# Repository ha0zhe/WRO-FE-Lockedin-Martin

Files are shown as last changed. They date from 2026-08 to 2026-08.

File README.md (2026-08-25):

# WRO-FE-Lockedin-Martin

# Team information:
Team ID: FE-XXX-01
Team name: Lockedin Martin
Team members:
- Yuan Hao Zhe
- Liu Xinji
- Om Joshi Vaibhav

# Overview
Welcome to the github repository of team Lockedin Martin for WRO 2026.

The Wro FE competition consists of 2 rounds: the open round and the obstacle round. in the open round, the vehicle must autonomously drive 3 laps on a track with no obstacles and stop at its starting position. in the obstacle round, the vehicle must navigate 3 laps on a track containing red and green traffic signs, turning right when encountering a red sign and left when encountering a green sign. For the obstacle round, the vehicle must also autonomously parallel-park in a parking lot that is demarcated by magenta blocks. 

All the information about the vehicle, including technical specifications, the design process and how it works, can be found in the engineering journal. The wiring diagram can be found in the schemes folder, the CAD models under the models folder, and the code in the src folder. 

Our team uses  dual microcontroller setup for this competition: the Openmv H7 plus for blob detection and navigation. and the RP2040 zero for sensor reading. code for specific functions of the H7, such as UART reading and blob detection, can be found in the files with names beginning with H7_ in the src folder. the RP2040 sensor reading code can be found in the same folder, compiled in one script.

# Build details
The chassis is printed at 0.20 mm nozzle diameter using PLA filament. The number of walls we used is 4 and the infill percentage is 15%. The infill pattern is grid.

Sandpaper may need to be used when assembling the chasis, if the fit is too tight.

The screws and nuts used to mount the steering mechanism must be snug, but not tight enough to hinder the actuation of the steering mechanism. 

The electronics are all connected using jumper cables without the need for soldering, with the exception of the power distribution board, which is direct soldered to the step down buck converters. More details can be found in the engineering journal. when soldering, keep the iron temperature at about 350 degrees and use liberal amounts of flux. be careful when holding the components with alligator clips as they might damage some delicate components on the board.

To charge the Lipo battery, a dedicated Lipo charger, such as the HOTA D6 Pro, must be used to avoid damaging the battery. do not discharge the battery below 3v and do not overcharge it over 4.2v

# Software details

Openmv IDE is used to run and debug the H7 code, while Arduino IDE is used for the RP2040. Thonny could also be used for the H7 if the camera is not needed e.g. when testing the UART.

Openmv IDE's threshold is used to tune the CIELAB color thresholds used in blob detection. As much as possible, refer to Openmv's excellent documentation and tutorials.

For the code to be saved on the H7, you must save it on the H7's internal memory as main.py. This can be done manually, through dragging and dropping files in file manager, or it can be done in the Openmv IDE in File --> save script under Openmv cam

To setup Thonny for Openmv H7 plus:
1. Install Thonny, then Run → Select interpreter.
2. Choose "MicroPython (generic)" from the interpreter dropdown (there's no dedicated OpenMV entry — generic is correct since it just      talks raw REPL over serial).
3. Pick the port your H7 Plus enumerates as (or leave on auto-detect if it's the only device attached).
4. Click OK — Thonny's shell should show the >>> REPL prompt, and the Files pane will let you browse/edit files directly on the camera's internal flash or SD card.

To setup Openmv Ide for Openmv H7 plus:
1. Download and install OpenMV IDE from openmv.io/pages/download — no separate board package needed, unlike Arduino.
2. Plug in the H7 Plus via USB, click Connect (bottom-left plug icon).
3. If prompted with a firmware update on first connect — accept it. It'll ask whether to erase the internal filesystem: say No if you      have scripts stored on internal flash you want to keep, otherwise Yes for a clean start. It flashes over DFU automatically (green       LED fades in/out during the process) and reconnects when done.
4. Open helloworld_1.py or your own script, hit the Play (bottom-left run) button — you'll get a live frame buffer view alongside           serial console output, which is what makes it good for tuning your blob-detection thresholds.

To setup Arduino Ide for RP2040 Zero:
1. Add the board package URL. Open Arduino IDE → File → Preferences → paste this into "Additional Boards Manager URLs":
   https://github.com/earlephilhower/arduino-pico/releases/download/global/package_rp2040_index.json
   (If you already have another URL      there, e.g. for ESP32, separate them with a comma.)
3. Install the core. Tools → Board → Boards Manager → search "pico" → install "Raspberry Pi Pico/RP2040/RP2350" by Earle F. Philhower,     III. This is the community core (not the official Arduino-Mbed one) — it's the one with full RP2040 peripheral support (PIO,            multicore, etc.) and is what you're already using per your Serial/Serial1/Serial2 debugging.
4. Select the board. Tools → Board → Raspberry Pi RP2040 Boards → Waveshare RP2040 Zero. If your installed core version doesn't list it    specifically, "Generic RP2040" also works fine for a Zero.
5. Upload. Hold BOOT, plug in via USB (or hold BOOT and tap RESET if already connected), release once the RPI-RP2 drive appears.           Arduino should now show a COM/tty port — select it and upload normally. After the first proper Arduino sketch is flashed, subsequent    uploads happen automatically over USB without needing BOOT mode again. If not, hold down the boot button, connect the RP2040, select
   and connect to the DFU port n the tools menu. After uploading the code, you should be able to connect via COM port in the same          tools menu
   
# Tips and tricks

1. Make sure all pin headers are tightly connected, especially for I2C. loose connections will degrade the high frequency clock signal and prevent it from working
2. Make sure to tighten all screws and nuts before testing. not doing so will result in inconsistent turn radii.
3. Make sure to wipe the TOF lens before testing it, to prevent oils from interfering with the reading
4. When tuning the color thresholds, use the narrowest thresholds that can still correctly identify the blocks under varying lighting conditions (e.g on different positions on the track)
5. do not touch the IMU while it is being tared.

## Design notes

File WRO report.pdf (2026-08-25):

## Engineering Journal

Team ID: FE-XXX-01
Team name: Lockedin Martin
Team members:
- Yuan Hao Zhe
- Liu Xinji
- Om Joshi vaibhav

## BOM

Component type | component | quantity
1x Main MCU | Openmv H7 plus | https://e.tb.cn/h.8k547RCXRMKPPMn?tk=YBlXTWm NGnR CA381
1x Sensor reading MCU | Waveshare RP2040 zero | https://e.tb.cn/h.8PjmAA171s06Ows?tk=IHOLTWmm ZNu HU591
2x TOF sensor | VL53L1X | https://e.tb.cn/h.8lDQ4xvxufmwdAn?tk=JVRuTWmoiV x MF937
1x Motor driver | DRV8874 | https://e.tb.cn/h.8PjKGGh9RIypMOC?tk=HPOsTWmo E9O CZ001 「D
1x IMU | BNO085 | https://kuriosity.sg/products/9dof-9-axis-accelerometer -gyroscope-magnetic-field-sensor-bno085?_pos=1&_ sid=b334db9a9&_ss=r
1x motor | 1020 coreless motor | https://e.tb.cn/h.8955D6mjnewGMLc?tk=FXHUTWmp d1r MF278
4x wheels | POLOLU 34mm silicone wheels | https://e.tb.cn/h.8lDlnlgMV7zfWEh?tk=kgliTWmKsee CZ005
1x servo | SG90 servo | https://kuriosity.sg/products/servo-motor-sg92r-180-36

| | 0-sg90-upgrade?_pos=1& _sid=28d788176&_ss=r
1x battery | TATTU R-LINE 2S 500MAH battery | https://hobbysquare.com.sg/collections/battery-2s-7-4v/products/tattu-r-line-7-4v-2s-550mah-95c-lipo-micro-battery-xt30
1x Buck converter | 5v buck converter | https://kuriosity.sg/products/dc-dc-step-down-buck-converter-3-3v-5v-12v-3a?variant=51054170308921
1x Buck converter | 3.3v buck converter | https://kuriosity.sg/products/dc-dc-step-down-buck-converter-3-3v-5v-12v-3a?_pos=3&_sid=1854b2fae&_ss=r
1x Battery lead | XT30 female lead | https://hobbysquare.com.sg/products/xt30-connector-male-and-female-2-pairs?_pos=4&_sid=2305c2fce&_ss=r
4x bearing | 2mm ID, 5mm OD, 2.5mm thick bearing | https://e.tb.cn/h.8k5j7aNDYUkgbZ3?tk=3Qu4TWmt2i L HU926
1x Motor gear | 10 tooth gear, 0.5mm ID | https://e.tb.cn/h.8k5SP1lUNwkpewx?tk=18RbTWmrF V0 MF278
1x Shaft gear | 30 tooth gear, 2mm ID | https://e.tb.cn/h.8957CbRobZdnOfa?tk=G1rCTWmsS 3b MF937 「0
2x Metal shaft | 2mm by 12mm stainless steel rod | https://e.tb.cn/h.895RU63o9vwlXqi?tk=8JWuTWmH8 mV MF168

## Mechanical design

Steering mechanism selection
- In an ideal steering mechanism, the path of all the wheels trace out circles that centres on the same point, which is the instantaneous centre of rotation (ICR) of the vehicle. This ensures that all wheels are tangential to the circular path that they travel, hence preventing lateral tire slippage. This reduces vibration and ensuring that the turning behaviour of the vehicle remains predictable
- A neutral steering mechanism has both front wheels being parallel to one another, while an ackermann steering mechanism has the inner wheel (the one closer to the ICR) turning more than the outer wheel. A reverse ackermann steering mechanism has the outer wheel turning more than the inner wheel.
- When a vehicle with a neutral steering mechanism turns rightwards, the centre of the circle that the inner (right) wheel traces lies to the right of that which the outer (left) wheel traces, resulting in lateral wheel slippage.
- An ackermann steering assembly remedies this problem by making sure the inner wheel turns more than the outer wheel. A reverse ackermann mechanism exacerbates this problem

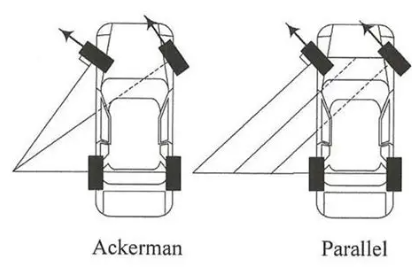
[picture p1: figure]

- A neutral or reverse ackermann mechanism offers different advantages. During high-speed cornering, weight shifts dramatically to the outer front tire. The outer tire generates the vast majority of cornering force and operates at a higher slip angle, while the unloaded inner tire contributes very little. Turning the outer tire more aggressively using a reverse ackermann mechanism maximizes peak cornering grip, improving high speed cornering performance.

- For our application, where precise and predictable low speed control is necessary to navigate around obstacles and to parallel park, the ideal steering mechanism would be the ackermann steering mechanism.

Ackermann mechanism key dimensions

In a standard ackermann steering mechanism, the front wheels are mounted to a steering rods that are connected by a steering linkage. The steering rods are angled in such a way that lines drawn through them intersect in the middle of the rear axle.

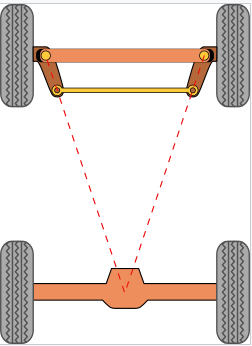
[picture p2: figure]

Motor and wheel sizing (from our LATEX document)

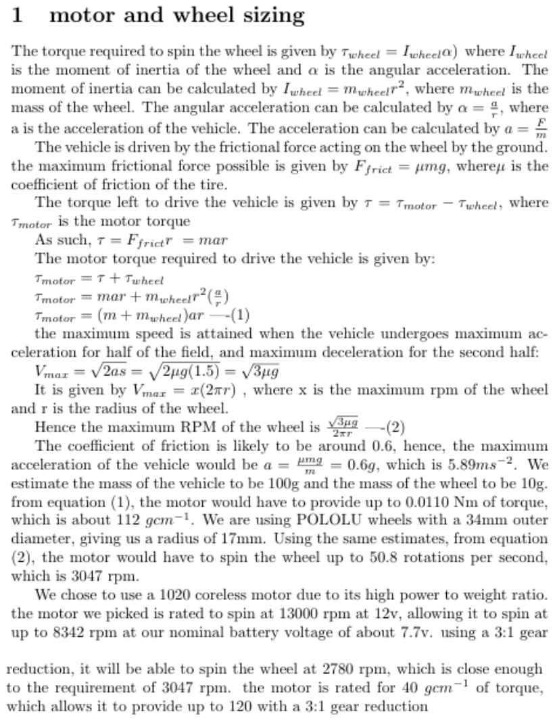
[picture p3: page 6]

Optimal CG location (from LATEX document)

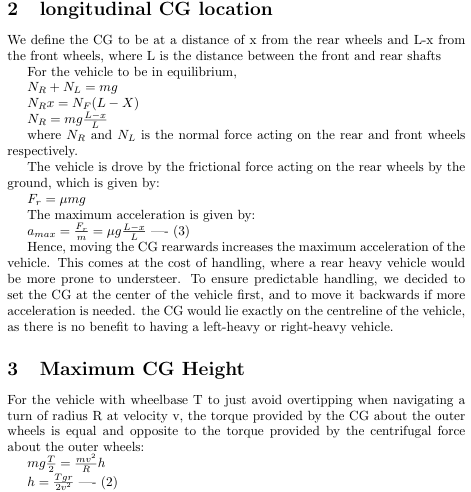
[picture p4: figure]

Mass requirement
- During braking, the motor driver shorts its terminals together, turning the motor into a generator and dissipating the vehicles kinetic energy.
- A lighter vehicle would brake better as it has less kinetic energy to dissipate
- Hence we aim to keep our vehicle mass as low as possible.

Chassis sizing(from our LATEX document)

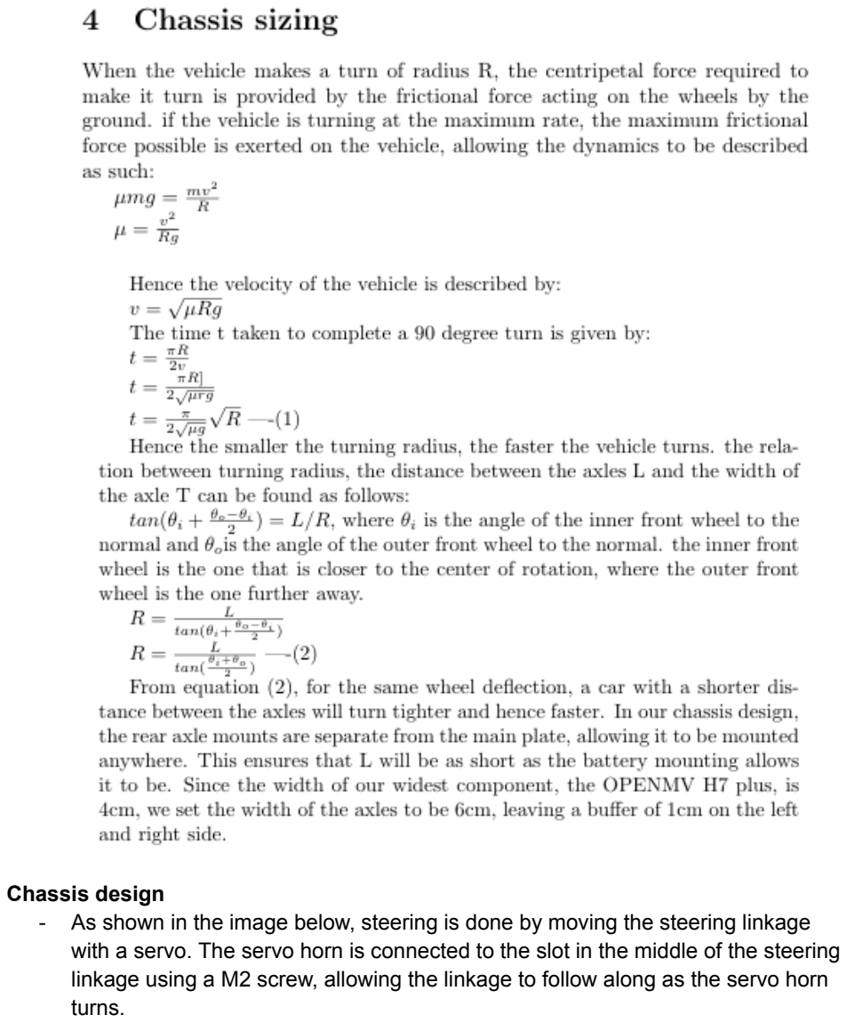
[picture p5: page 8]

Chassis design
- As shown in the image below, steering is done by moving the steering linkage with a servo. The servo horn is connected to the slot in the middle of the steering linkage using a M2 screw, allowing the linkage to follow along as the servo horn turns.

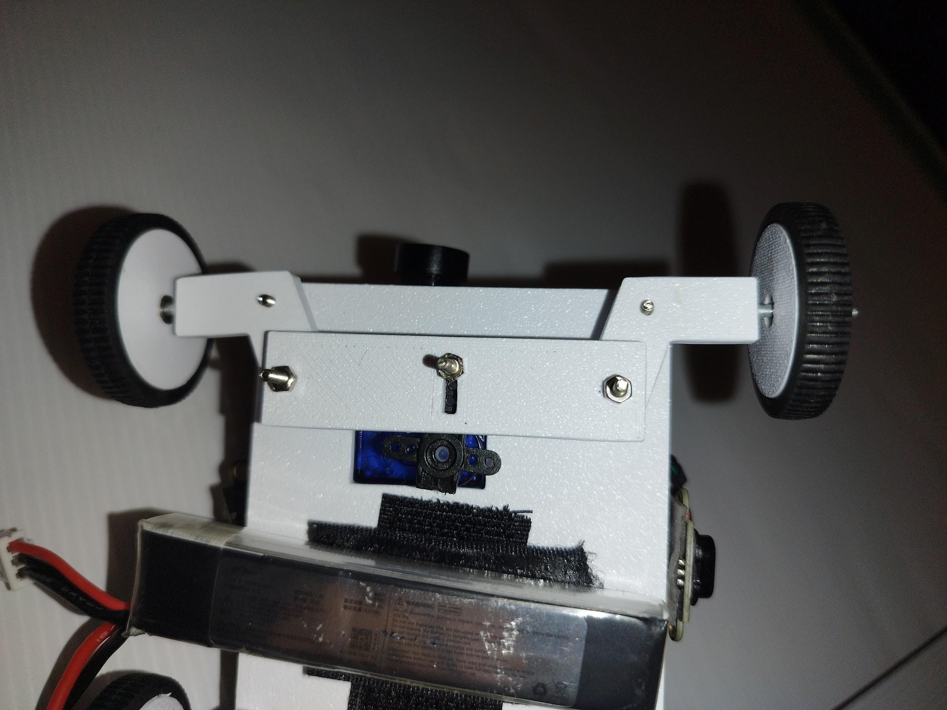
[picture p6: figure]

- As the chassis is designed before the mounting of the electronics is finalised, one of the key considerations behind our chassis design is to make it as modular as possible, so that it can accommodate as many configurations of electronics as possible. To accomplish this, we decided to mount the steering pins and linkage using M2 screws and nuts instead of 3d printing a mount. This allows us to freely adjust the distance of the steering mechanism from the main plate by using different numbers of nuts, hence allowing it to be connected to many different servos.

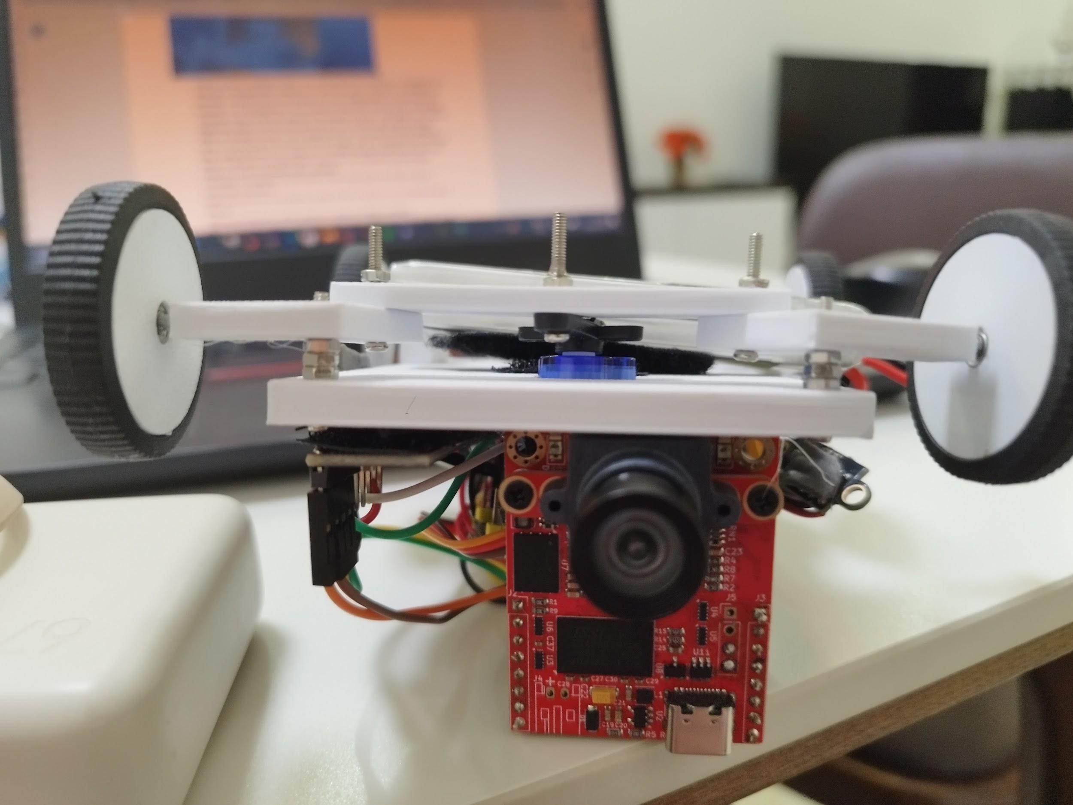
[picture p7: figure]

- The mounts for the rear shaft is also separate from the main plate, allowing them to be swapped out if different gears need to be used. The motor, front and rear shaft mounts, and servo are mounted using hot glue, making it easily removable with a penknife.
- The front wheels are mounted to a 2mm by 15mm metal shaft that is then inserted to the front steering arm. We cut it down to size from the 12mm by 2mm shaft used for the rear wheels
- The battery is mounted on the bottom of the main plate, to make room for electronics on the top.
- After trial and error, we ended up using 0.2mm of tolerance for all parts to get a snug fit
- We used bearings for all the wheels to minimize rolling resistance
- We used a 2mm stainless steel metal rod for the shaft because 3d printed shafts would be too weak. We used off-the-shelf plastic gears for the gear reduction because they are machined more precisely than 3d printed parts, reducing the friction between the gear teeth.
- All electronics are mounted using velcro, for easy removal

## Power Management

Voltage draw
- All electronics are powered by 3.3V and 5V buck converters which step down battery voltage to 3.3V and 5V respectively
- VL53L1X must be powered off 3.3V for the logic level to be 3.3v, as the RP2040 zero is not 5V tolerant
- All other components can be powered off 5V, but we chose to power the rp2040 off 3V to free up space on the 5V rail and improve wire management
- The BNO085 is powered off the 3.3V regulator of the OpenmvH7 plus due to its proximity to it, hence freeing up space on the 3.3V rail and improving wire management
component | Input voltage tolerance | Logic level tolerance | Input voltage | Logic level
DRV8874 motor driver | 4.5-37V | 1.8V-5.5V input | 5V and battery voltage
Openmv H7 Plus | 3.6-5V | 3.3V output Input up to 5V | 5V
RP2040 Zero | 2.5-3.3V (3V3 pin) 4.3-5.5V (5V/USB pin) | 3.3V input and output | 3.3V
VL53L1X TOF sensor | 2.6v-5.5V | 3.3V-5V input and output, output level shifted to Power supply voltage | 3.3V
BNO085 IMU | 3.0v-5.0V | 3.3V-5V input and output, output level shifted to Power supply voltage | 3.3V
SG90 servo | 4.8v-6.0V | 3.3V to 5V input | 5V

3.3V

Current draw

component | Maximum current draw
DRV8874 motor driver | 2.1A continuous, 4.4A peak with current limiting enabled
Openmv H7 Plus | ~350 mA

RP2040 zero | ~100 mA (40-50mA when both ARM Cortex-M0+ cores run at 125 MHz, 50mA max from GPIO pins)
VL53L1X TOF | ~20 mA continuous, 40 mA when the laser fires
BNO085 | ~20 mA
SG90 servo | ~750 mA when stalled
TOTAL | ~3.36 A continuous, ~5.70 A peak

Buck converter specifications

The the 5V buck converter powers the SG90 servo and the OpenmvH7 plus, which powers the BNO085 IMU, while the 3.3V buck converter powers the RP2040 and two VL53L1X TOF sensors. The DRV8874 is powered directly by the battery. Both buck converters are able to supply the required current.

Buck converter type | Input voltage | Maximum output current | Maximum current drawn
5V | 7-26V | 1.8A | 1.12A
3V | 5.3-26V | 2.5A | 0.14A

## Buck converter setup

- The two buck converters are soldered to a perfboard as such

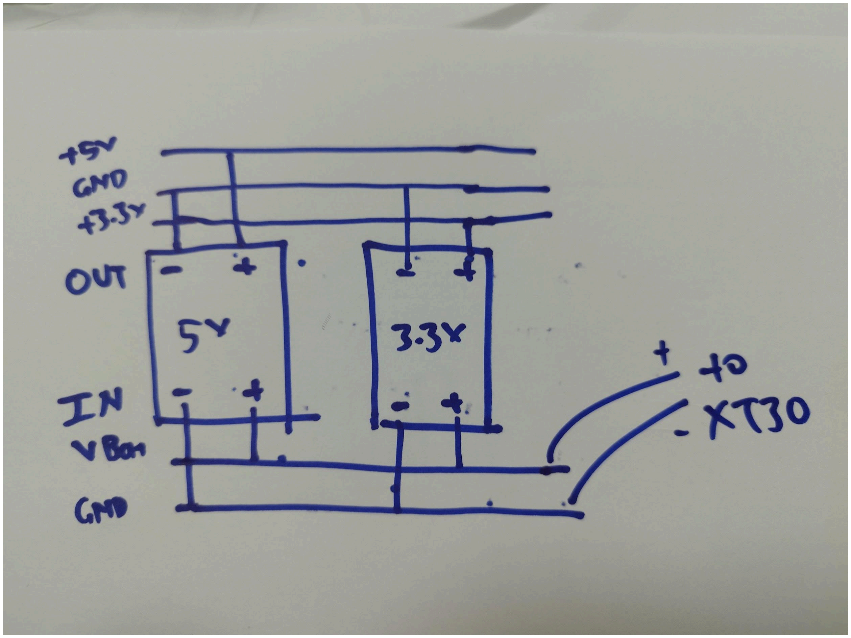
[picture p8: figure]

- The positive input of both buck converters are soldered to the same rail, which is connected to the positive lead of the battery via an XT30 female connector
- Likewise, the negative input of both buck converters are soldered to the same rail
- The negative output of both buck converters are soldered to the same rail
- The 3.3v output and 5v output are soldered to the rails above and below the GND rail respectively

BATTERY TYPE SELECTION
The ideal battery must be:
1. supply a high enough voltage and current throughout the duration of the run to be able to easily power all components on the vehicle
2. be light so total weight is reduced, allowing for faster braking and more predictable cornering
3. be thin enough so the car can sit lower to the ground, reducing the CG height and hence improving the turn radius

Hence we decided to use lithium polymer (Lipo) battery packs as they are generally lighter and smaller than lithium ion or double A battery packs of the same capacity and voltage.
Lipo batteries are also widely available, coming in a wide range of voltages, current ratings and capacities, making it easier to find one that is optimal

Characteristics of lipo batteries:

- A lipo battery has a maximum voltage of 4.2v per cell when fully charged and can be discharged down to a minimum voltage of approximately 3.0v, below which the battery becomes permanently damaged due to electrochemical effects.
- the battery C rating shows its approximate current rating: maximum continuous current = capacity (in Ah) x C rating
- as the battery discharges, the open circuit voltage per cell decreases plateaus at about 3.8 volts per cell, approximately following this graph:

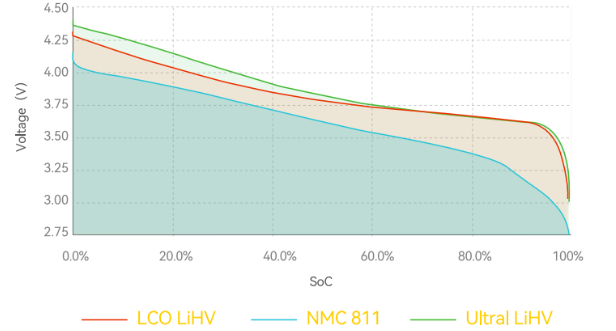
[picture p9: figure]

- due to battery internal resistance, the terminal voltage (v = V-RI) will always be lower than the open circuit voltage when current is flowing
- the internal resistance increases if the system draws sustained and high current. lithium ions must move through electrolytes, separators and electrodes in order to react and supply electricity. As this process takes time, continuously drawing high current may deplete the supply of lithium electrons in certain parts of the battery, resulting in chemical disequilibrium, increasing the battery internal resistance and causing the terminal voltage to sag even more. This effect is not significant if current draw is much lower than the maximum rating, hence the importance of choosing a battery with a high C rating.

Lipo selection: Tattu R-Line 550mAh 2s

As the maximum continuous current draw is 3.36A, the vehicle would draw a maximum of 168 mAh of charge over a 3 minute run time, which is 15.3% of the total charge capacity (550mAh x
2) of the battery. This gives us an open circuit voltage of approximately 3.9V per cell at the end of the run, with a total open circuit voltage of 7.8V. Using a high estimate of internal resistance of 30mOhm and the maximum peak current of 5.70A, the maximum voltage sag would be 0.03 x

5.70 = 1.01 V. since the battery is rated for 95C of continuous current draw, which is much higher than the maximum current draw of our vehicle, we expect the internal resistance to stay constant during the run. Hence the minimum terminal voltage during the run would be about 7.7V, leaving a 0.7v buffer to the minimum input voltage of the 5v buck converter. Hence, we are confident that the Tattu R-Line 550mah 2s will be able to easily power all of our components across the duration of the run.

## Electronics

## Sensor architecture

- We use one microcontroller to read sensor data and another one to run the blob detection and navigation algorithms, and to control the vehicle movement. This is done to increase the speed of the control loop.
- Reading a VL53L1X sensor takes up to 20ms using the longest ranged detection mode. Reading two sensors takes anywhere from 20ms to 40ms, depending on how synchronised the two sensors are – something that varies with each run. Since sensor reading is blocking, with other parts of the code waiting for it to finish, doing this using the same microcontroller that runs blob detection and navigation code would slow down the control loop by at least 20ms.
- In comparison, if a separate microcontroller is reading sensor data, both the sensor reading and the blob detection + navigation code can run simultaneously, with the data being sent over by UART once it is collected. Since reading an approximately 40 byte data packet via a UART with 115200 baudrate only takes about 3.5 milliseconds, a dual microcontroller setup would be much faster than a single microcontroller.

## Choice of components

When choosing components, we went with 2 main criteria
1. Smaller is better
- our chassis calculations show that smaller vehicles are able to turn faster and tighter, shaving time off our runtime and improving maneuverability
2. Simpler is better
- Based on our previous experience, a simpler system has less points of failure and is easier to debug, leading to a more reliable and repairable system

RP2040 zero

The RP2040 zero was chosen for various reasons:
- Size
- The RP2040 zero is one of the smallest microcontrollers that has the functionality that we need. This is due to its innovative design that places pins on 3 sides of the board, while most other microcontrollers only use 2 sides
- Affordability
- The RP2040 zero’s 4 USD price is very affordable compared to alternatives from arduino and STM32, which usually cost at least 10 USD
- Functionality
- It uses a Dual-core Arm Cortex M0+ processor, flexible clock running up to 133 MHz. This is much faster than alternatives like the arduino nano, which only runs up to 16 MHz
- It has 29 × multi-function GPIO pins (20× via edge pinout, others via solder points), 2 × SPI, 2 × I2C, 2 × UART, 4 × 12-bit ADC, 16 × controllable PWM channels
- This is more than our requirements of 1 UART and at least 1 I2C bus, giving us great flexibility in using additional peripherals in the future
- Every GPIO pin can be routed to any of the 8 × Programmable I/O (PIO) state machines. PIO machines are used to quickly and precisely read the quadrature encoder used with the motor.
- Language compatibility and flexibility
- The RP2040 zero can be programmed using c++ in the arduino IDE, something that we are already familiar with. C++ also runs faster as it is a lower level programming language.
- It can be programmed using micropython and Thonny, which may prove useful if we decide to use micropython to keep the code simpler to read, and if its speed is sufficient. One of the team members is also much more experienced in python

Computer vision

- We decided not to use openCV because it requires a single board computer, such as a raspberry pi, running a full linux operating system to set up and use. A single board computer is not only large by itself, it also has a comparatively high power consumption, hence requiring a battery with a higher capacity. This leads to a larger chassis and a higher all up weight, reducing the speed and maneuverability of our vehicle. An operating system, dependency management and toolchains are also needed to run opencv, making it complex to setup and use and hence prone to errors. As we only need to run simple blob detection, we do not need the advanced computer vision and machine learning algorithms provided by opencv, making it overkill for our application
- We decided to go with openmv because it can be run on cheap, low power and compact microcontrollers without the need to install operating systems, and is simple to setup using the openmv IDE. Openmv libraries also have a wide range of algorithms to detect and track simple objects, such as blob detection, line detection, and the rectangle detection that is used to find apriltags. Furthermore, the documentation is excellent, with extensive tutorials and guides.
- We decided to go with the openmvH7 plus because blob detection is relatively simple and does not require the computing power of more modern modules such as the openmv n6. The camera resolution is also greatly improved over the base H7, at 5MP instead of 0.3MP. This allows it to detect the traffic signs from further away and track the centroids of the signs more precisely, hence allowing the vehicle to navigate more precisely. This is especially important since we plan to replace the stock lens with 50 degree FOV with one that has a higher FOV of 105 degrees.
- The openmv h7 plus has 3 pins dedicated hardware PWM pins, 2 uarts and 2 I2C buses, allowing it to interface with all of the peripherals that we need.

Distance sensor
- Distance sensors are mounted to the side of our vehicle for wall detection and avoidance.
- We chose to use Time of flight (TOF) sensors instead of ultrasonic sensors because ultrasonic sensors tend to be unreliable, with fluctuating values and a tendency to malfunction and cause the i2c bus to hang. Using multiple ultrasonic sensors together will also result in interference, further degrading the readings.
- We chose to use the VL53L1X due to its long range and small form factor. Its maximum range is 400cm, which is long enough to detect the walls at the side, even after accounting for the low reflectivity of the matte black surface of the walls, which reduce the range to about 200cm
- The range of the VL53L1X is also adjustable, giving us the option to trade detection range for update rate and resistance to ambient lighting

IMU
- We chose the BNO085 because it has the lowest rotation vector drift rate, about 2 degrees per minute, out of all the options we have, even without having to use the magnetometer. This is done using the Hillcrest Labs' proprietary SH-2 sensor fusion engine (MotionEngine)
- The sensor fusion software uses dynamic gyroscope zero-rate bias estimation to reduce gyroscope drift, and uses an extended kalman filter alongside accelerometer data to produce an accurate angular position.
- This eliminates our dependence on magnetometers, which require careful calibration in every different location, and whose reading is frequently unreliable due to the changing magnetic fields from the motor.

Motor + wheel + encoder
- We chose the POLOLU 34mm wheel because it is available in local electronics stores, making it easy to replace.
- We chose to use a 1020 coreless motor due to its high power to weight ratio and small size (see mobility management for more details)
- We hot glued an encoder designed for N20 gearmotors onto the front shaft of the coreless motor, and attached a gear to the back shaft using superglue. The encoder is mounted on the front shaft due to the motor terminals on the back blocking it.
- N20 gearmotor encoders are more common than other encoders, such as optical encoders, and are likely to have better documentation, hence the choice to use them

Motor driver
- The DRV8874 was chosen because its current rating is high enough to power the motor.
- It is also able to use both the PWM and PH/EN control modes, allowing for flexibility in how we control the motor.
- The documentation behind the motor driver is also extensive, with the datasheet explaining small details such as how the current limiter works

Buck converters
- We used the buck converters from our local electronics shop because it is readily available, making it easy to find replacements if we damage it during soldering, or if one of them is defective

# Wiring diagram

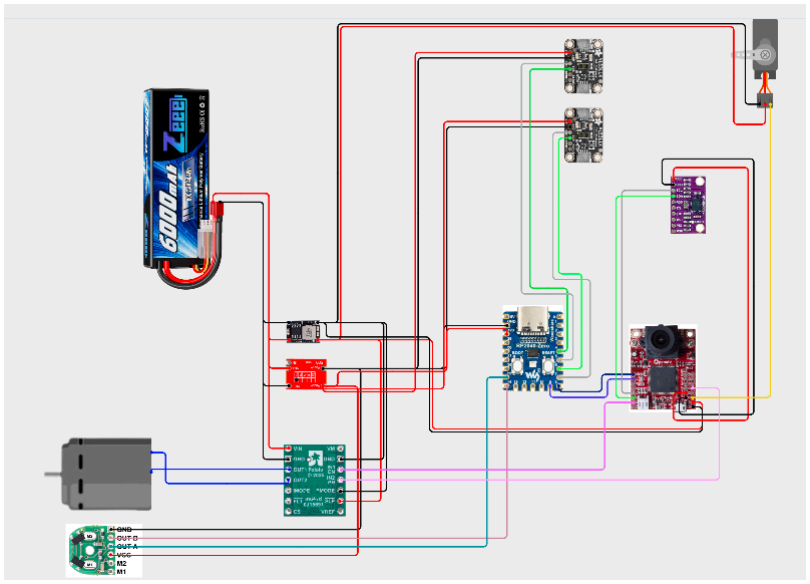
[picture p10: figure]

The wiring diagram for our vehicle can be found here: Cirkit Designer IDE (https://app.cirkitdesigner.com/project/a0f62c62-ac20-4be2-ba1d-bf362a7d67d6)

Rp2040 zero to VL53L1X
The VL53L1X TOF sensor communicates with the RP2040 Zero using I2C. each sensor uses its own i2c bus instead of sharing a bus, to reduce the complexity of our code.
- TOF 1 SDA → GPIO 4 (i2c bus 1 SDA)
- TOF 1 SCL → GPIO 5 (i2c bus 1 SCL)
- TOF 2 SDA → GPIO 6 (i2c bus 2 SDA)
- TOF 2 SCL → GPIO 7 (i2c bus 2 SCL)
The RP2040 zero only has 2 I2C buses, so any additional TOFs used must share an i2c bus. Since all VL53L1X sensors share the same default address, the addresses of all the TOFs on the bus must be reassigned during startup so the i2c bus knows which sensor it is talking to. This can be done by connecting their XSHUT pins to GPIO pins, turning on the sensors one by one using and reassigning their addresses individually.

RP2040 to encoder

- The motor encoder uses quadrature encoding and sends data to the RP2040 using digital HIGH/LOW signals
- It can be read using any GPIO pins on the RP2040 zero, though most encoder libraries require the two pins to be adjacent to one another
- OUT A → GPIO 14
- OUT B → GPIO 15
If the encoder outputs negative values when the vehicle is moving forward, just swap the two connections.

RP2040 to Openmv H7 Plus
- The RP2040 zero communicates with the OpenmvH7 using UART. the RP2040 uses UART bus 1 (GPIO 8 and 9), and the Openmv H7 Plus uses UART bus 1 (P0, P1)
- GPIO 8 (TX1)→ P0(RX1)
- GPIO 9 (RX1)→ P1(TX1)

Openmv H7 Plus to DRV8874
- The Openmv H7 Plus controls the DRV8874 motor driver using Phase/enable mode instead of pwm mode. Pulling the phase pin on the DRV8874 high or low determines the direction that the motor is spinning in, while applying a PWM signal to the enable pin determines the motor speed.
Phase/enable mode is preferable to pwm mode as it has a more linear relationship between PWM duty cycle and motor speed, making it easier to tune the motor speed.
- The PH pin is connected to P9, and the EN pin is connected to P6
- PH → P9
- EN → P6 (PWM signal)
- NOTE: the EN pin on the motor driver and the servo signal wire should not be connected to pins on the OpenmvH7 that share the same timer (eg. P7 and P8), as the frequencies of their PWM signals are different (50hz on the servo, 20kHz on the motor driver), hence requiring separate timers.
- The motor wires are connected to the output pins
- OUT1 → motor terminal
- OUT2 → motor terminal
- 5V must be connected to Vsleep on the DRV8874 to set the current limiting to 4A, and GND must be connected to PMODE on the DRV8874 to enable EN/PH mode.
- Vsleep → 5v output on buck converter
- PMODE → GND on buck converter

Openmv H7 Plus to BNO085
- The BNO085 IMU communicates with the Openmv H7 Plus using I2C. the I2C 2 bus is used.
- SDA → P5 (I2C 2 SDA)
- SCL → P4 (I2C 2 SCL)

Power electronics (see power management for details) Battery voltage
- The DRV8874 is powered off battery voltage
5V buck converter
- 5V buck converter is used to power the Openmv H7 Plus, and the SG90 servo
- Connect all the Vin pins to the 5V rail, and all the ground pins to the ground rail
- 5V must be connected to Vsleep on the DRV8874 to set the current limiting to 4A, and GND must be connected to PMODE on the DRV8874 to enable EN/PH mode.
3.3V buck converter
- 3.3V buck converter is used to power the VL53L1X and the RP2040 Zero
- Connect all the Vin pins to the 3.3V rail, and all the ground pins to the ground rail
- The BNO085 is powered off the 3.3v regulator on the Openmv H7 Plus

## IMU calibration

- The accelerometer and gyroscope of the IMU do not require calibration on start, as they are calibrated at the factory
- The magnetometer can be calibrated by running the calibration code in src, and moving the sensor around in a figure 8 pattern until the magnetometer calibration accuracy level reaches 3.
- For our application, we do not use the magnetometer as the changing magnetic fields from the motor will affect the accuracy of the readings. As such, we take the heading from the game rotation vector output, instead of the rotation vector output on the IMU.

## Color threshold calibration

- The LAB color space is used instead of RGB, as any changes in brightness would affect all 3 of the R,G,B readings, affecting the accuracy of the detection. In LAB color space, the L (lightness) term separates pure brightness from the actual chromatic color, allowing us to account for surface gloss and shadows

- Calibration is done in the OPENMV IDE threshold editor, as follows
- Load the blob detection script onto the board → run the script to capture a image in the frame buffer → go to tools - machine vision- threshold editor → adjust the A and B sliders until the blob you are trying to detect becomes white

## Obstacle management (open)

Start condition:
- Power is supplied to the vehicle by turning on a switch connected to the positive lead of the battery
- A switch connects pin P2 to ground. If the switch is closed, P2 will be pulled low and the start condition would be true. Only then would the vehicle run.

turning methods

We considered 2 main ways to detect the turn direction and turns: using the camera or the side TOF sensors:
- detect turn direction
- using camera:
- check whether orange or blue blob is detected first

OR

- Using side TOF: check which side registers large jump in reading first
- detect turns using
- Side TOF: turn when one side registers large jump in reading
- Camera: turn as soon as either orange or blue blob is detected
- May set a distance delay: turn only when an orange or blue blob is detected and the encoder increases by X counts, hence making sure the vehicle clear the inner walls, no matter the track configuration

Upon further testing, we found that camera blob detection triggers turning more reliably, provided the color thresholds were tuned well.

Since a smaller radius turn also means a faster turn, as shown in the mechanical design section, we use a lower speed when turning.

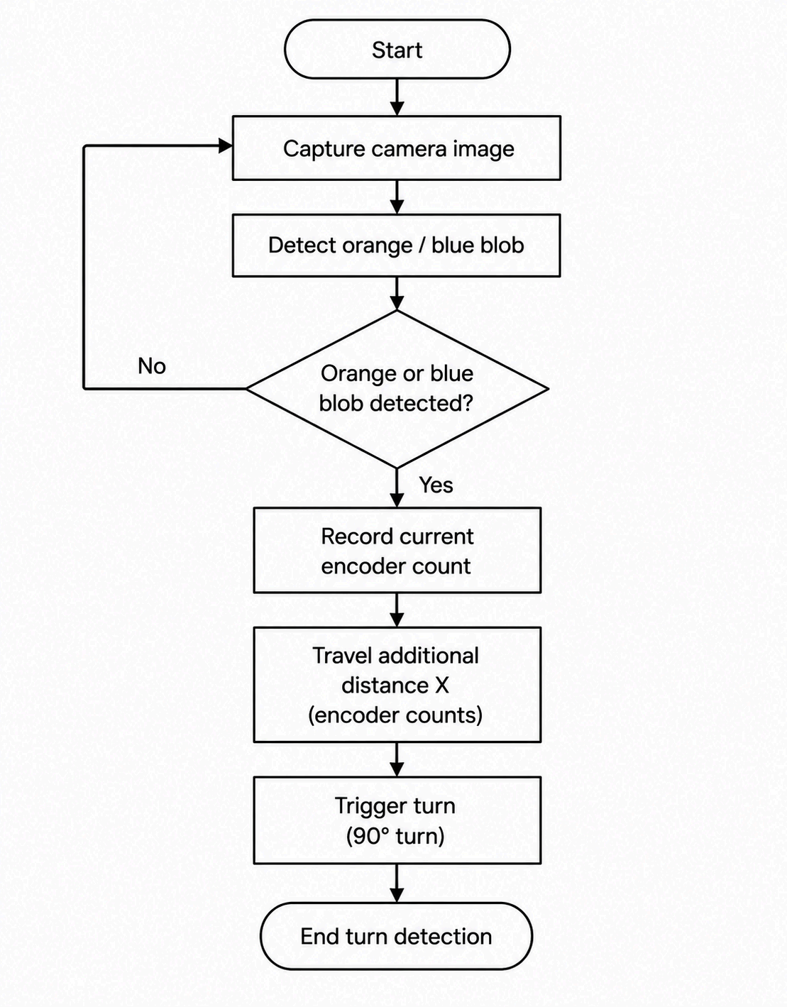
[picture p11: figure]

IMU PID
- Throughout the whole run, we run a PID loop using the IMU heading to ensure that the vehicle remains parallel to the walls
- If we were to hard code the turns wiithout a PID loop, differences in wheel friction, chassis vibration and unpredictable wheel slip would cause the vehicle to fall out of alignment and crash into the walls.

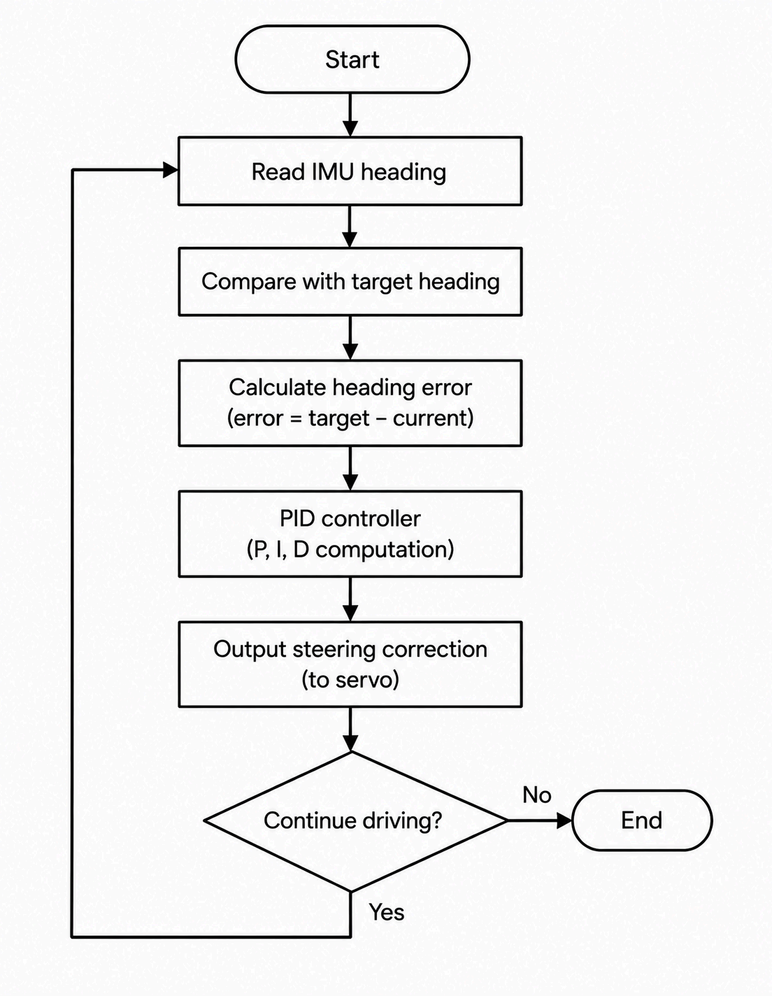
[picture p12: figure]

Corner counting
- We simply count the number of turns registered by theIMU

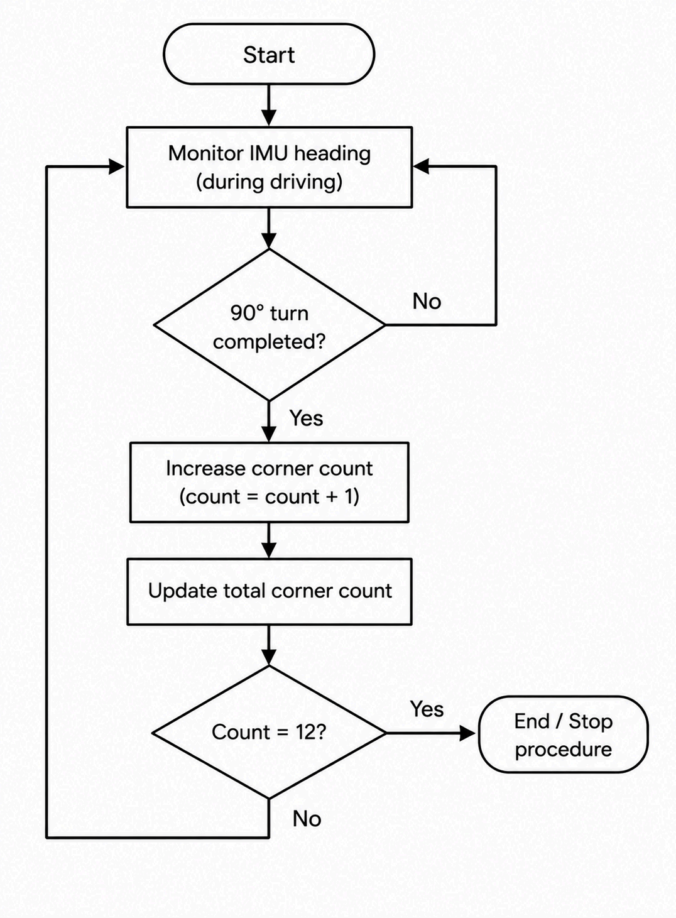
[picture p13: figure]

Driving straight
- Apart from the PID loop, we also use the TOF sensors for wall avoidance:
- If the left TOF registers a reading of less than dmin, the setpoint heading changes by 20 degrees to the right
- If the right TOF registers a reading of less than dmin, the setpoint heading changes by 20 degrees to the left
- The setpoint headings return to normal after the vehicle is more than dmin away from the walls
- This serves as a final failsafe if the IMU PID loop fails to keep the vehicle away from the walls

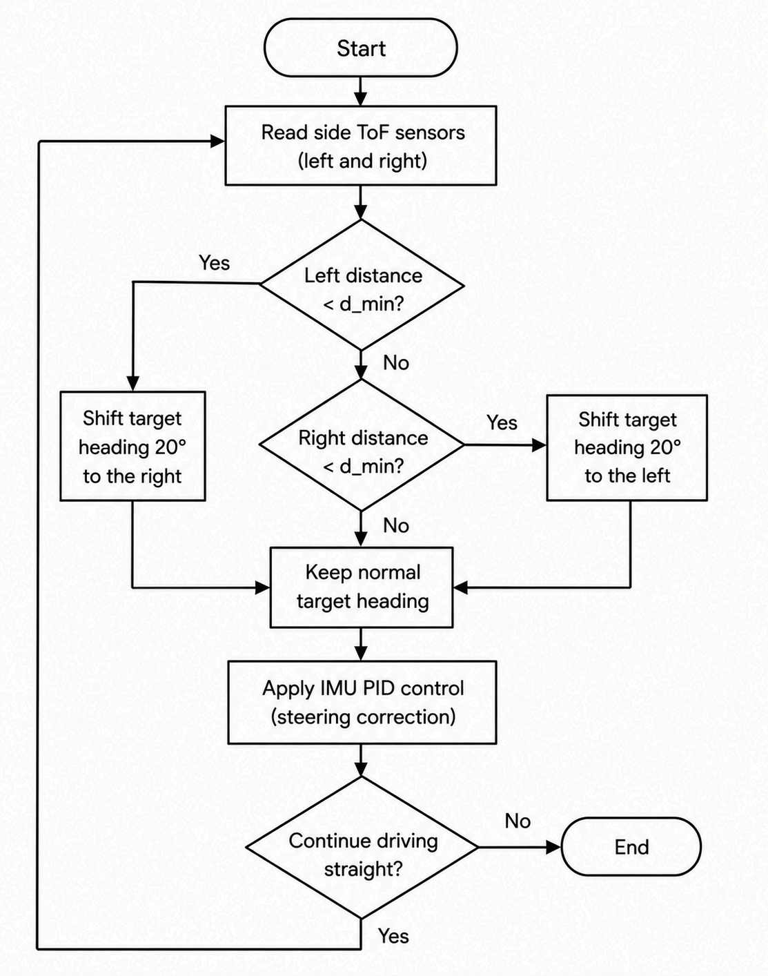
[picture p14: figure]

Stopping
- After 12 corners are detected the vehicle comes to a stop after travelling for a certain number of encoder counts
- The speed is cut in half to ensure that the wheels do not slip, hence giving an accurate encoder reading.

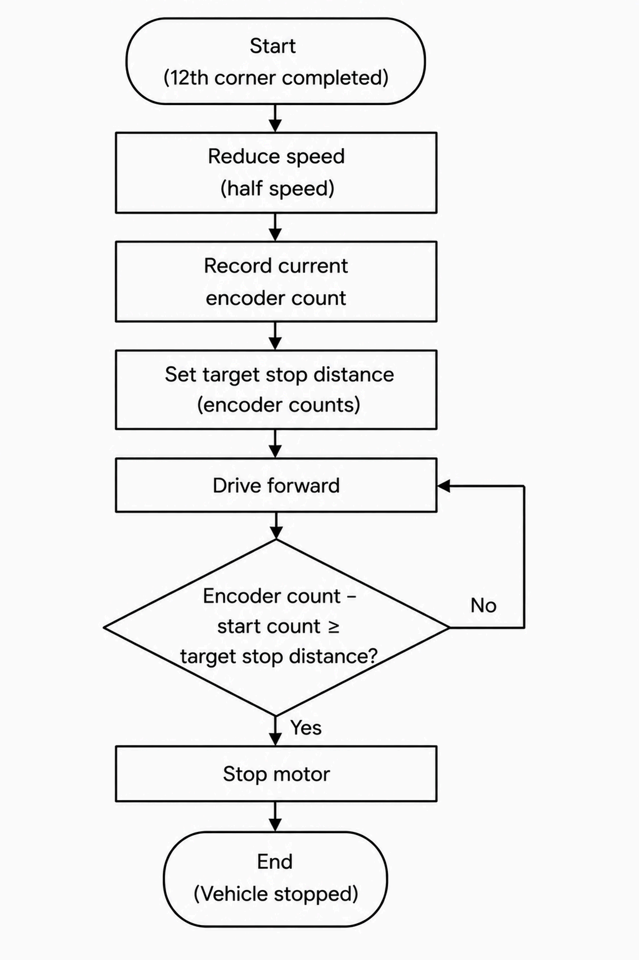
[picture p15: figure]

## Obstacle management (obstacle)

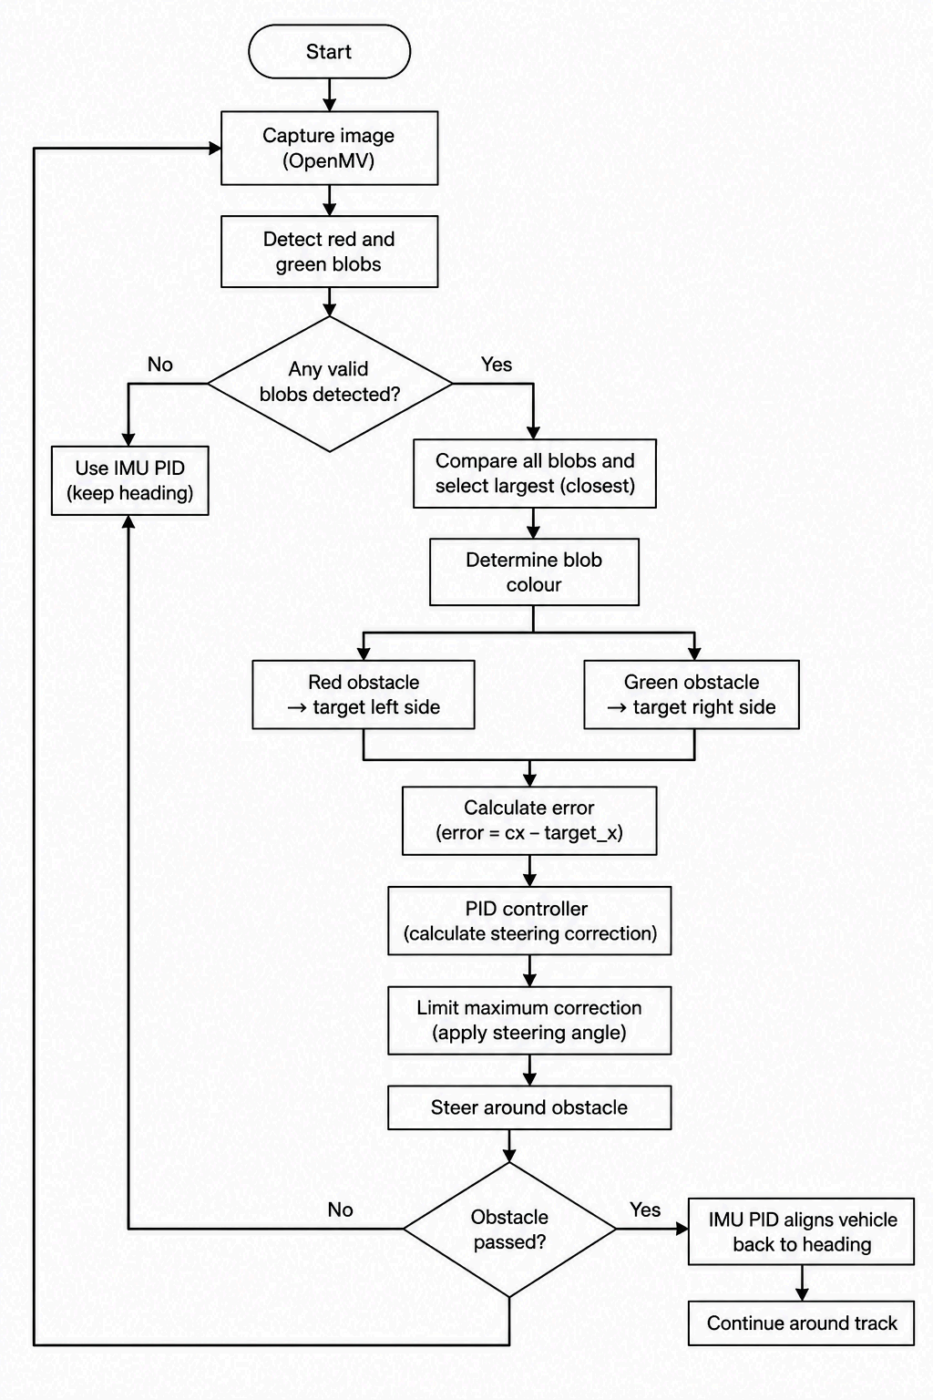
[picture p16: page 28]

1. The red and green traffic signs are detected using the blob detection functions provided by OpenMV. Colour thresholds are used to separate red and green objects from the rest of the camera image.
2. All valid red and green blobs in the camera frame are compared. The blob with the greatest pixel area is selected, as a larger apparent area generally indicates that the traffic sign is closer to the vehicle.
3. Once an obstacle is detected, its colour determines the required passing side. For a red traffic sign, the servo direction is changed so that the block is positioned towards the left side of the camera frame, allowing the vehicle to pass the obstacle on its right. For a green traffic sign, the servo direction is changed so that the block is positioned towards the right side of the frame, allowing the vehicle to pass the obstacle on its left. The vehicle then adjusts servo direction to move back onto its original course.
4. The horizontal position of the detected blob is compared with the required target position, and the resulting error is passed into a PID controller. The controller continuously adjusts the steering servo so that the blob centroid approaches the desired position in the camera image.
5. The steering correction generated by the PID controller is limited to prevent excessively sharp steering commands. As the vehicle moves, a new camera frame is captured and the blob centroid is recalculated. This forms a closed-loop system:

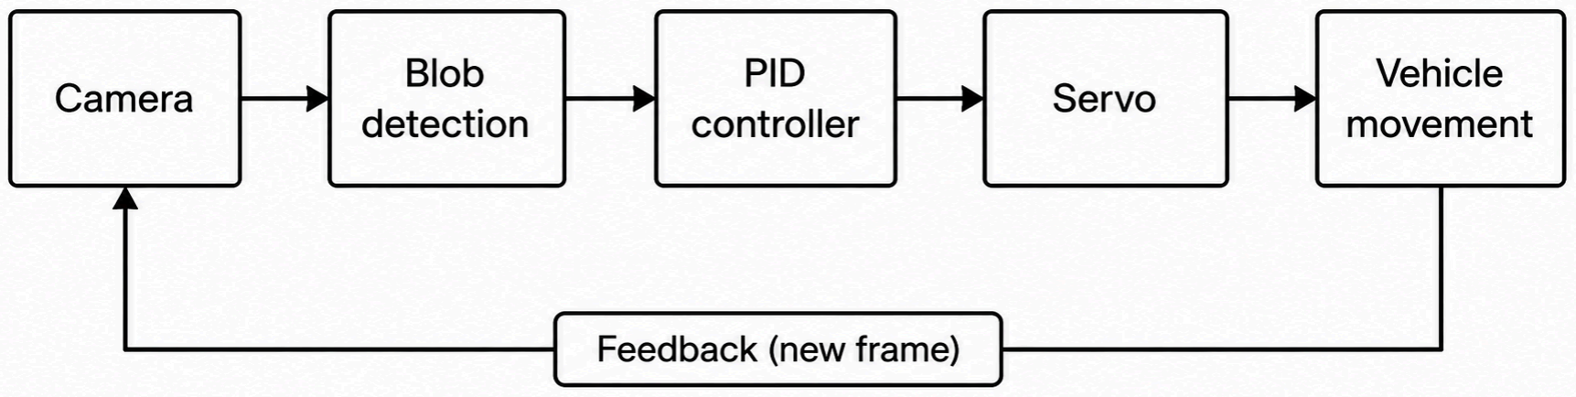
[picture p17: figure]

The process repeats continuously instead of relying on a completely hardcoded avoidance path.

6. The relative size of the blob is also monitored. As the vehicle approaches an obstacle, the blob occupies more pixels in the image. This is done through assessing the height and width in pixels. Once pixel threshold is met, the avoidance protocol is started.
7. After the obstacle has been passed, obstacle guidance is discontinued and control returns to the IMU-based heading controller. The IMU PID controller steers the vehicle back towards its original straight heading so that it travels approximately parallel to the track walls.
8. During turning, if another valid red or green blob is detected while the vehicle is approaching a corner or changing its direction, the vehicle returns to the obstacle-avoidance controller. A 90 degree turn can only be performed when no obstacle is detected.

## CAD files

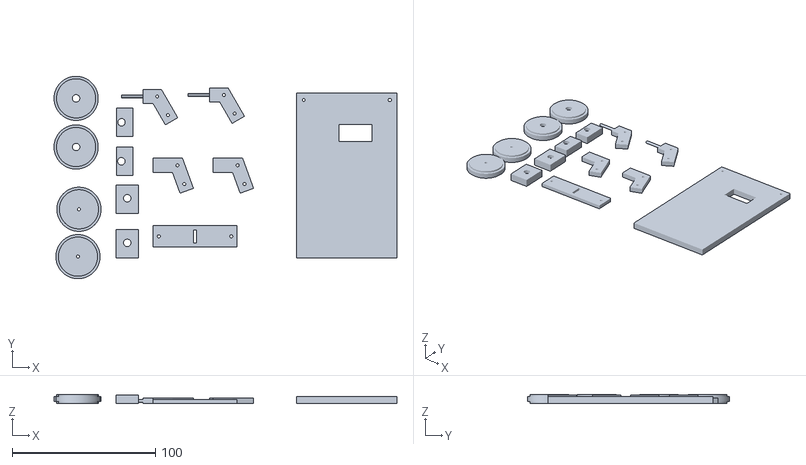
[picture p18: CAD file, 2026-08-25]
models / WRO CHASSIS FINAL.stl
239.1 x 141.1 x 6.60

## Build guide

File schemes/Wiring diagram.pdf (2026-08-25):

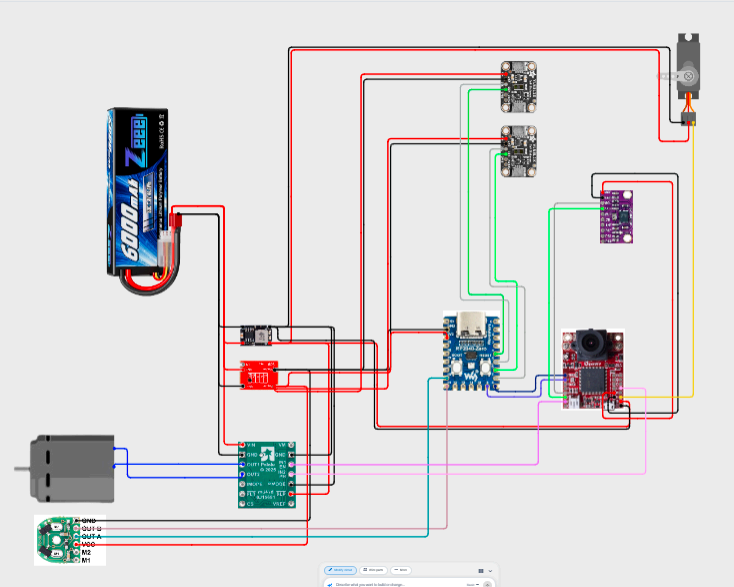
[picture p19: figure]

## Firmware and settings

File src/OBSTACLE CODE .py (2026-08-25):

# ============================================================
# WRO 2026 FUTURE ENGINEERS
# OBSTACLE CHALLENGE
#
# COMPLETE PYTHON CONTROL PROGRAM
#
# Existing hardware ports are UNCHANGED:
#
# UART          = UART(1)
# IMU           = I2C(2)
# Servo         = P8
# Motor DIR     = P9
# Motor PWM     = P6
#
# ============================================================


# ============================================================
# ORIGINAL UART CODE
# ============================================================

from machine import UART
import re


# define variables below

encoder_count = 0
wheel_revolutions = 0
tof0 = 0
tof1 = 0


uart = UART(1, 115200)

uart.init(
    115200,
    bits=8,
    parity=None,
    stop=1)


buf = b""


pattern = re.compile(
    r'encoder count:\s*(\d+),\s*'
    r'tof0:\s*(\d+),\s*'
    r'tof1:\s*(\d+)')


def read_UART():

    global buf, encoder_count, tof0, tof1, wheel_revolutions

    if uart.any() > 0:

        buf += uart.read(
            uart.any())

        if b'\n' in buf:

            line_byte, buf = buf.split(b'\n',1)

            line_string = (line_byte.decode('utf-8').strip())

            match = pattern.search(line_string)

            if match:

                encoder_count = int(match.group(1))

                tof0 = int(match.group(2))

                tof1 = int(match.group(3))

                wheel_rotations = (encoder_count/(28 * 3))

            print("Parsed -> Encoder:",encoder_count,"TOF0:",tof0,"TOF1:",tof1)

        else:

            print("Failed to parse string structure")


# ============================================================
# ORIGINAL IMU CODE
# ============================================================

from machine import I2C, Pin
from utime import ticks_ms, ticks_diff, sleep_ms
import math
from bno08x import *


i2c1 = I2C(
    2,
    freq=100000,
    timeout=200000
)


bno = BNO08X(
    i2c1,
    debug=False
)


print(
    "BNO08x I2C connection : Done\n"
)


bno.enable_feature(
    BNO_REPORT_GAME_ROTATION_VECTOR,
    10
)


bno.set_quaternion_euler_vector(
    BNO_REPORT_GAME_ROTATION_VECTOR
)


print(
    "BNO08x sensors enabling : Done\n"
)


cpt = 0


def read_IMU():

    global cpt

    cpt += 1

    print(
        "cpt",
        cpt
    )

    R, T, P = bno.euler

    print(
        "Euler Angle\tX: {:+.3f}\tY: {:+.3f}\tZ: {:+.3f}".format(
            R,
            T,
            P
        )
    )

    if cpt == 10:

        bno.tare()


# ============================================================
# ORIGINAL SERVO CODE
# ============================================================

from machine import PWM, Pin


servo = PWM(
    Pin("P8"),
    freq=50,
    duty_ns=1_500_000)


def set_position(angle):

    pulse_us = (
        1000
        +
        (angle * 1000)
        //
        180)

    servo.duty_ns(
        pulse_us * 1000)


# Existing examples:
#
# set_position(25)   full right
# set_position(135)  full left
# set_position(80)   centre


# ============================================================
# ORIGINAL MOTOR CODE
# ============================================================

import time
from machine import PWM, Pin


dir_pin = Pin(
    "P9",
    Pin.OUT
)


speed = PWM(
    Pin("P6"),
    freq=20_000,
    duty_u16=0
)


def drive(
    direction,
    speed_percent
):

    dir_pin.value(
        direction
    )

    speed.duty_u16(
        (
            speed_percent
            *
            65535
        )
        //
        100
    )


# ============================================================
#
# NEW WRO OBSTACLE CHALLENGE CODE STARTS HERE
#
# ============================================================


import sensor


# ============================================================
# MOTOR DIRECTION
# ============================================================

FORWARD = 0
REVERSE = 1


# ============================================================
# STEERING
# =========================S===================================

STEERING_RIGHT = 25
STEERING_CENTRE = 80
STEERING_LEFT = 135


MAX_BLOB_STEERING = 40

MAX_IMU_STEERING = 35


# ============================================================
# SPEEDS
# ============================================================

# Slow parking/start speed to reduce wheel slip

LEAVING_SPEED = 50

NORMAL_SPEED =70

AVOID_SPEED = 60

TURN_SPEED = 65

PARKING_SPEED = 60


# ============================================================
# WHEEL / ENCODER
# ============================================================

ENCODER_COUNTS_PER_REV = (
    28 * 3
)


# CHANGE THIS
# Measure your actual wheel diameter

WHEEL_DIAMETER_MM = 34


WHEEL_CIRCUMFERENCE_MM = (
    math.pi
    *
    WHEEL_DIAMETER_MM
)


# ============================================================
# ROUND SETTINGS
# ============================================================

ROUND_TIME_LIMIT_MS = (
    3 * 60 * 1000
)


TARGET_LAPS = 3

TURNS_PER_LAP = 4


# Distance travelled after fourth corner
# before confirming that the lap is complete.

LAP_CONFIRM_DISTANCE_MM = 150


# ============================================================
# LEAVING PARKING LOT
# ============================================================

BACKUP_DISTANCE_MM = 40


RIGHT_TURN_TIME_MS = 900

STRAIGHT_CLEAR_TIME_MS = 800

LEFT_TURN_TIME_MS = 900


# ============================================================
# TOF
# ============================================================

# Change to False if tof0 is physically on RIGHT

TOF0_IS_LEFT = True


WALL_DETECT_DISTANCE_MM = 500


TURN_OPENING_DISTANCE_MM = 800


TURN_OPENING_CONFIRM_MS = 250


# ============================================================
# CAMERA
# ============================================================

IMAGE_WIDTH = 160

IMAGE_HEIGHT = 120


BLOB_ROI = (
    0,
    20,
    160,
    100
)


BLOB_MIN_PIXELS = 100

BLOB_MIN_AREA = 100


# ============================================================
# COLOUR THRESHOLDS
#
# IMPORTANT:
#
# Calibrate these using OpenMV Threshold Editor.
#
# These are placeholders only.
#
# WRO specifies:
#
# Red pillar:
# RGB 238,39,55
#
# Green pillar:
# RGB 68,214,44
#
# Parking marker:
# RGB 255,0,255
#
# OpenMV uses LAB thresholds so you MUST calibrate these
# under your competition lighting.
# ============================================================


RED_THRESHOLDS = [
    (24, 76, 21, 127, 51, 8)
]


#GREEN_THRESHOLDS = [(14, 25, -128, -4, 11, 42)]
GREEN_THRESHOLDS = [(17, 100, -128, -19, -128, 52)]

MAGENTA_THRESHOLDS = [
    (20, 81, 28, 98, -128, 31)
]


# ============================================================
# TRAFFIC SIGN DIMENSIONS
#
# Official pillar width is 50 mm.
# ============================================================

TRAFFIC_SIGN_WIDTH_MM = 50


# Desired horizontal clearance from pillar

DESIRED_CLEARANCE_MM = 120


MIN_OFFSET_PX = 18

MAX_OFFSET_PX = 55


# ============================================================
# PASSING CONDITIONS
# ============================================================

PASS_BLOB_PIXELS = 1500


PASS_ERROR_TOLERANCE_PX = 7


PASS_CONFIRM_FRAMES = 3


BLOB_CLEAR_FRAMES = 4

# Blob-loss confirmation. A near blob is only treated as passed if it
# disappeared near an image edge for several consecutive frames.
BLOB_LOST_CONFIRM_FRAMES = 3
BLOB_PASS_EDGE_MARGIN_PX = 15
BLOB_ABORT_MISSING_FRAMES = 6


# ============================================================
# BLOB PID
# ============================================================

BLOB_KP = 0.4

BLOB_KI = 0

BLOB_KD = 0


NEAR_BLOB_PIXELS = 900


NEAR_D_MULTIPLIER = 2.0


FAR_ERROR_CLAMP = 55

NEAR_ERROR_CLAMP = 28


# Change to -1 if steering is reversed

BLOB_STEERING_SIGN = -1


# Amount of IMU heading correction mixed
# into obstacle guidance

IMU_BLOB_CORRECTION = 0.15


# ============================================================
# IMU PID
# ============================================================

IMU_KP = 0.3

IMU_KI = 0

IMU_KD = 0


# Change to -1 if necessary

IMU_STEERING_SIGN = 1


# ============================================================
# 90 DEGREE TURN
# ============================================================

TURN_TOLERANCE_DEG = 3


TURN_CONFIRM_FRAMES = 4


# Assumes positive yaw = CCW

CW_TURN_CHANGE = -90

CCW_TURN_CHANGE = 90


# ============================================================
# PARKING
# ============================================================

# IMPORTANT:
#
# Enter your actual robot length.
#
# Official parking-space length:
#
# 1.5 x robot length
#

ROBOT_LENGTH_MM = 100


PARKING_SPACE_LENGTH_MM = (
    1.5
    *
    ROBOT_LENGTH_MM
)


# Official parking-space width = 200 mm

PARKING_SPACE_WIDTH_MM = 200


# Desired distance to outer wall

PARK_WALL_DISTANCE_MM = 120


PARK_DISTANCE_TOLERANCE_MM = 15


PARK_HEADING_TOLERANCE_DEG = 3


PARK_CONFIRM_FRAMES = 5


# Magenta marker size required to begin parking

MAGENTA_TRIGGER_PIXELS = 700

# Require both magenta parking markers before starting the parking sequence.
MAGENTA_SECONDARY_TRIGGER_PIXELS = 250
MAGENTA_CONFIRM_FRAMES = 2


# Parking manoeuvre distances.
#
# These must be calibrated on your actual vehicle.


PARK_FORWARD_ALIGN_MM = 120


PARK_REVERSE_FIRST_MM = 150


PARK_REVERSE_SECOND_MM = 170


PARK_FINAL_MIN_DISTANCE_MM = 80

# Prevent endless reverse travel during final alignment. Tune on the real car.
PARK_FINAL_MAX_DISTANCE_MM = 180

# Steering/yaw response reverses while driving backwards on an Ackermann car.
PARK_REVERSE_STEERING_SIGN = -1


# Parking steering angles

PARK_LEFT_IN = STEERING_LEFT

PARK_LEFT_COUNTER = STEERING_RIGHT


PARK_RIGHT_IN = STEERING_RIGHT

PARK_RIGHT_COUNTER = STEERING_LEFT


# ============================================================
# GLOBAL CONTROL VARIABLES
# ============================================================

control_buf = b""


control_encoder = 0

control_tof0 = 0

control_tof1 = 0


left_tof = 0

right_tof = 0


current_yaw = 0


course_direction = None


robot_state = "WAIT_FOR_START"


state_start_time = 0

state_start_encoder = 0


round_start_time = None


straight_heading = 0

turn_target = 0


lap_count = 0

turns_this_lap = 0


waiting_for_lap_confirmation = False

lap_corner_encoder = 0


parking_enabled = False


opening_start_time = None


blob_pass_count = 0

blob_missing_count = 0

last_blob_size = 0
last_blob_cx = None


resume_state_after_blob = (
    "NORMAL_DRIVING"
)


current_sign_colour = None


turn_confirm_count = 0


imu_counter_control = 0

imu_tared_control = False


parking_side = None

parking_heading = 0

parking_confirm_count = 0


magenta_detect_count = 0

# Saved start encoder when a parking stage is interrupted by obstacle avoidance.
parking_resume_encoder_start = None


# ============================================================
# START BUTTON
#
# Uses OpenMV built-in user button.
#
# This does NOT change any of your external pin assignments.
# ============================================================

try:

    from pyb import Switch

    start_switch = Switch()

except:

    start_switch = None


# For bench testing only.
#
# Competition:
# KEEP FALSE

ALLOW_AUTOSTART_FOR_TESTING = True

if start_switch is None and not ALLOW_AUTOSTART_FOR_TESTING:
    print("WARNING: pyb.Switch() is unavailable. Competition start will not work until the built-in start button API is confirmed.")


def start_button_pressed():

    if (
        ALLOW_AUTOSTART_FOR_TESTING
    ):

        return True


    if start_switch is None:

        return False


    try:

        return start_switch()

    except:

        return False


# ============================================================
# SAFE UART READER
#
# Original read_UART() remains unchanged.
# ============================================================

control_pattern = re.compile(
    r'encoder count:\s*(-?\d+),\s*'
    r'tof0:\s*(\d+),\s*'
    r'tof1:\s*(\d+)'
)


def read_control_UART():



    global control_buf

    global control_encoder

    global control_tof0

    global control_tof1

    global left_tof

    global right_tof


    if uart.any() > 0:

        incoming = uart.read(
            uart.any()
        )


        if incoming:

            control_buf += incoming


    while b'\n' in control_buf:

        line_byte, control_buf = (
            control_buf.split(
                b'\n',
                1
            )
        )


        try:

            line_string = (
                line_byte
                .decode('utf-8')
                .strip()
            )

        except:

            continue


        match = (
            control_pattern.search(
                line_string
            )
        )


        if match:

            control_encoder = int(
                match.group(1)
            )


            control_tof0 = int(
                match.group(2)
            )


            control_tof1 = int(
                match.group(3)
            )


            if TOF0_IS_LEFT:

                left_tof = (
                    control_tof0
                )

                right_tof = (
                    control_tof1
                )


            else:

                left_tof = (
                    control_tof1
                )

                right_tof = (
                    control_tof0
                )


# ============================================================
# SAFE IMU READER
#
# Original read_IMU() remains unchanged.
# ============================================================

def read_control_IMU():

    global current_yaw

    global imu_counter_control

    global imu_tared_control


    try:

        R, T, P = bno.euler


        # Your original code displays:
        #
        # R = X
        # T = Y
        # P = Z
        #
        # Use Z as yaw.

        current_yaw = P


        imu_counter_control += 1


        if (
            imu_counter_control == 10
            and
            not imu_tared_control
        ):

            try:

                bno.tare()

            except:

                print('imu tare fail')


            imu_tared_control = True


            print(
                "IMU TARED"
            )


    except Exception as error:

        print(
            "IMU ERROR:",
            error
        )


# ============================================================
# MOTOR STOP
# ============================================================

def robot_stop():

    speed.duty_u16(0)


# ============================================================
# ENCODER DISTANCE
# ============================================================

def encoder_distance_mm(
    difference
):

    revolutions = (
        abs(difference)
        /
        ENCODER_COUNTS_PER_REV
    )


    return (
        revolutions
        *
        WHEEL_CIRCUMFERENCE_MM
    )


# ============================================================
# ANGLE WRAPPING
# ============================================================

def wrap_angle(angle):

    while angle > 180:

        angle -= 360


    while angle < -180:

        angle += 360


    return angle


# ============================================================
# CAMERA INITIALISATION
# ============================================================

sensor.reset()


sensor.set_pixformat(
    sensor.RGB565
)


sensor.set_framesize(
    sensor.QQVGA
)

sensor.set_vflip(True)
sensor.set_hmirror(True)

sensor.skip_frames(
    time=2000
)


sensor.set_auto_gain(
    False
)


sensor.set_auto_whitebal(
    False
)


print(
    "CAMERA READY"
)


# ============================================================
# PID CONTROLLER
# ============================================================

class PIDController:

    def __init__(
        self,
        kp,
        ki,
        kd
    ):

        self.kp = kp

        self.ki = ki

        self.kd = kd


        self.integral = 0

        self.previous_error = 0

        self.previous_time = None


    def reset(self):

        self.integral = 0

        self.previous_error = 0

        self.previous_time = None


    def calculate(
        self,
        error,
        d_multiplier=1.0
    ):

        now = ticks_ms()


        if self.previous_time is None:

            dt = 0.03


        else:

            dt = (
                ticks_diff(
                    now,
                    self.previous_time
                )
                /
                1000
            )


            if dt <= 0:

                dt = 0.001


        self.integral += (
            error
            *
            dt
        )


        derivative = (
            error
            -
            self.previous_error
        ) / dt


        output = (
            self.kp
            *
            error
            +
            self.ki
            *
            self.integral
            +
            self.kd
            *
            d_multiplier
            *
            derivative
        )


        self.previous_error = error

        self.previous_time = now


        return output


# ============================================================
# PID OBJECTS
# ============================================================

blob_PID = PIDController(
    BLOB_KP,
    BLOB_KI,
    BLOB_KD
)


imu_PID = PIDController(
    IMU_KP,
    IMU_KI,
    IMU_KD
)


parking_heading_PID = PIDController(
    1.0,
    0,
    0.12
)


parking_distance_PID = PIDController(
    0.08,
    0,
    0.02
)


# ============================================================
# CHANGE STATE
# ============================================================

def change_state(
    new_state
):

    global robot_state

    global state_start_time

    global state_start_encoder


    robot_state = new_state


    state_start_time = (
        ticks_ms()
    )


    state_start_encoder = (
        control_encoder
    )


    print(
        "STATE ->",
        new_state
    )


# ============================================================
# DETERMINE CW / CCW
#
# Wall LEFT  = CW
# Wall RIGHT = CCW
# ============================================================

def detect_course_direction():

    global course_direction


    print(
        "LEFT TOF:",
        left_tof,
        "RIGHT TOF:",
        right_tof
    )


    left_wall = 0 < left_tof <= WALL_DETECT_DISTANCE_MM
    right_wall = 0 < right_tof <= WALL_DETECT_DISTANCE_MM

    if left_wall and not right_wall:

        course_direction = "CW"
        print("CW TRACK")
        return True

    elif right_wall and not left_wall:

        course_direction = "CCW"
        print("CCW TRACK")
        return True

    elif left_wall and right_wall:

        if left_tof < right_tof:
            course_direction = "CW"
            print("CW TRACK")
        else:
            course_direction = "CCW"
            print("CCW TRACK")
        return True

    course_direction = None
    print("NO VALID STARTING WALL DETECTED")
    return False


# ============================================================
# CAMERA TRAFFIC-SIGN DETECTION
#
# Returns:
#
# blob
# colour
#
# Largest red/green blob is assumed closest.
# ============================================================

def detect_traffic_sign():

    img = sensor.snapshot()


    red_blobs = img.find_blobs(

        RED_THRESHOLDS,

        roi=BLOB_ROI,

        pixels_threshold=(
            BLOB_MIN_PIXELS
        ),

        area_threshold=(
            BLOB_MIN_AREA
        ),

        merge=True
    )


    green_blobs = img.find_blobs(

        GREEN_THRESHOLDS,

        roi=BLOB_ROI,

        pixels_threshold=(
            BLOB_MIN_PIXELS
        ),

        area_threshold=(
            BLOB_MIN_AREA
        ),

        merge=True
    )


    candidates = []


    for blob in red_blobs:

        candidates.append(
            (
                blob,
                "RED"
            )
        )


    for blob in green_blobs:

        candidates.append(
            (
                blob,
                "GREEN"
            )
        )


    if not candidates:

        return None, None


    closest = max(
        candidates,

        key=lambda item:

            item[0].pixels
    )


    blob = closest[0]

    colour = closest[1]


    img.draw_rectangle(
        blob.rect
    )


    img.draw_cross(
        (blob.cx,
        blob.cy)
    )


    return (
        blob,
        colour
    )


# ============================================================
# PARKING CAMERA
#
# Detect:
#
# RED/GREEN traffic signs
# MAGENTA parking markers
#
# in same frame.
# ============================================================
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

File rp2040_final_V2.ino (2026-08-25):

#include <Wire.h>
#include <VL53L1X.h>
#include "pio_encoder.h"

// Encoder setup on GPIO 14 & 15
PioEncoder encoder(14); 

const uint8_t sensorCount = 2;
VL53L1X sensors[sensorCount];

// Store latest valid readings
static uint16_t last_tof0 = 0;
static uint16_t last_tof1 = 0;

// Readiness flags
bool tof0_data_ready = false;
bool tof1_data_ready = false;
int encoder_count = 0;

void setup()
{
  encoder.begin();
  
  Serial.begin(115200);
  unsigned long start = millis();
  while (!Serial && (millis() - start < 2000)) {} 

  // Initialize Hardware UART2 (Serial2)
  Serial2.setTX(8);
  Serial2.setRX(9);
  Serial2.begin(115200);
  delay(2000); 
  Serial.println("RP2040 UART Initialized.");

  // --- Bus 0 Configuration (GPIO 4 & 5) ---
  Wire.setSDA(4);
  Wire.setSCL(5);
  Wire.begin();
  Wire.setClock(400000);

  // --- Bus 1 Configuration (GPIO 6 & 7) ---
  Wire1.setSDA(6);
  Wire1.setSCL(7);
  Wire1.begin();
  Wire1.setClock(400000);

  // Initialize Sensor 0 on Wire (Bus 0)
  sensors[0].setTimeout(500);
  sensors[0].setBus(&Wire); // Assign to First Bus
  if (!sensors[0].init()) {
    Serial.println("Failed to detect sensor 0 on Wire (GPIO 4/5)");
    while (1);
  }
  sensors[0].setDistanceMode(VL53L1X::Long);
  sensors[0].setMeasurementTimingBudget(50000);
  sensors[0].startContinuous(50);

  // Initialize Sensor 1 on Wire1 (Bus 1)
  sensors[1].setTimeout(500);
  sensors[1].setBus(&Wire1); // Assign to Second Bus
  if (!sensors[1].init()) {
    Serial.println("Failed to detect sensor 1 on Wire1 (GPIO 6/7)");
    while (1);
  }
  sensors[1].setDistanceMode(VL53L1X::Long);
  sensors[1].setMeasurementTimingBudget(50000);
  sensors[1].startContinuous(50);
}

void loop()
{
  encoder_count = encoder.getCount();

  // Continuously update ToF sensor values
  for (uint8_t i = 0; i < sensorCount; i++) {
    if (sensors[i].dataReady()) {
      sensors[i].read();
      if (i == 0) { 
        last_tof0 = sensors[i].ranging_data.range_mm;
        tof0_data_ready = true;
      }
      if (i == 1) { 
        last_tof1 = sensors[i].ranging_data.range_mm;
        tof1_data_ready = true;
      }
    }
  }

  // Print data once both sensors have a fresh measurement
  if (tof0_data_ready && tof1_data_ready) {
    // Serial2 Output
    Serial2.print("encoder count: ");
    Serial2.print(encoder_count);
    Serial2.print(", tof0: ");
    Serial2.print(last_tof0);
    Serial2.print(", tof1: ");
    Serial2.println(last_tof1);

    // USB Serial Output
    Serial.print(encoder_count);
    Serial.print(",");
    Serial.print(last_tof0);
    Serial.print(",");
    Serial.println(last_tof1);

    // Reset flags
    tof0_data_ready = false;
    tof1_data_ready = false;
  }
}

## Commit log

2026-08-01 Add files via upload
    rp2040_final_V2.ino contains c++ code for the rp2040 zero to read 2x VL53L1X TOF sensors and 1x n20 gearmotor encoder, as well as the UART code used to send the data to the openmvH7 plus
    H7... scripts contain micropython code for the openmv h7 to read via UART the data sent by the rp2040, as well as to interface with the BNO085 IMU, SG90 servo and the DRV8876 motor driver
2026-08-04 Create Chassis design
2026-08-04 Create Powertrain selection
2026-08-04 Rename Chassis design to Mechanical design
2026-08-04 Rename Powertrain selection to Power management
2026-08-04 Create Sensor reading code
2026-08-06 Add files via upload
    added IMU magnetometer calibration code. magnetometer data is needed for the imu to fuse with accelerometer and gyroscope data to come up with the rotation vector. since background magnetic fields va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
    calibration status ranges from 1 to 3, with 3 being the most accurate calibration
    the code runs calls the calibration function, and if calibration status>=2 for 5 seconds, saves the calibration
2026-08-06 Update Power management
2026-08-12 Update h7_imu_script.py
    removed unnecessary sensor reports
2026-08-12 Rename rp2040_final_V2.ino to RP2040 SENSOR READING FINAL
2026-08-22 Update RP2040 SENSOR READING FINAL
2026-08-25 Update and rename calibration.py to src/IMU_magnetometer_calibration.py
2026-08-25 Rename WRO CHASSIS FINAL.stl to schemes /WRO CHASSIS FINAL.stl
    [WRO CHASSIS FINAL.stl]
2026-08-25 Rename WRO CHASSIS FINAL.stl to WRO CHASSIS FINAL.stl
    [WRO CHASSIS FINAL.stl]
2026-08-25 Rename Untitled document.pdf to schemes/Wiring diagram.pdf
2026-08-25 Create Wiring diagram link
